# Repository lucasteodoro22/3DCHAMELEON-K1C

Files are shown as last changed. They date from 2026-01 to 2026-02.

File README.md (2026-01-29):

# 3DChameleon K1C - Sistema de Troca Automática de Filamentos





## 📋 Visão Geral

Este projeto é uma implementação adaptada do **3DChameleon Mk4** para a impressora **Creality K1/K1C**, utilizando comunicação serial integrada com o **Klipper**. O sistema permite troca automática de até 4 filamentos diferentes durante a impressão, com controle completo via interface Klipper.

### 🎯 Características Principais

- **Troca Automática**: Até 4 filamentos diferentes
- **Integração Klipper**: Controle completo via G-code
- **Sistema de Buffer**: Alimentação automática de filamento (já implementado)
- **Coletor de Purga**: Sistema inteligente de coleta de purga
- **Estado Persistente**: Salva estado entre reinicializações
- **Corte Automático**: Sequência segura de corte de filamento

### 🔧 Integrações Já Implementadas

Este projeto utiliza e adapta os seguintes sistemas já prontos:

#### 📦 **Sistema de Buffer Automático** (`FILAMENT_BUFFER_MOUNT.stl`)
- **Montagem**: Modelo STL customizado para Creality K1
- **Funcionalidade**: Alimentação automática quando buffer vazio
- **Sensores**: Microswitches NC para detecção de nível
- **Integração**: Completamente integrada ao firmware Arduino

#### 🐢 **Sistema de Buffer TurtleNeck** (`TurtleNeck-main/`)
- **Uso**: Sistema de buffer de filamento (TurtleNeck buffer)
- **Modelos**: `frame.stl`, `lid.stl`, `[a]_slide.stl`, `TN_horizontal mount.stl`
- **Integração**: Buffer de filamento compatível com montagem horizontal na Creality K1
- **Função**: Mantém reservatório de filamento para reduzir tensão na extrusora

#### 🔀 **Hub PTFE 3-para-1** (`ptfe-3-to-1-hub-model_files/`)
- **Distribuição**: `ptfe3to1hub_v2.stl` para 3 filamentos
- **Versões**: Full (`ptfe3x1_full.stl`) e Half (`ptfe3x1_half.stl`)
- **Integração**: Sistema de distribuição para múltiplos filamentos

---

## 🏗️ Arquitetura do Sistema

### Componentes Principais

#### 1. **Arduino Uno + CNC Shield v3** (`3dchameleon_serial.ino`)
- **Eixo Z**: Motor da extrusora (alimentação de filamento)
- **Eixo X**: Motor do seletor (seleção de ferramenta)
- **Servo Pin 11**: Coletor de purga (PURGA_COLETOR_PIN)
- **Sensores de filamento por ferramenta** (NC): T0=D9 (X Endstop), T1=D10 (Y Endstop), T2=D13 (SpnDir)
- **Sensor de filamento no hotend**: A3 (CoolEnd)
- **Sensor de alimentação** (NO): T1=A2 (Resume) — monitora filamento pré-carregado
- **Sensores de buffer** (NC): A0 (HOLD), A1 (ABORT)
- **Comunicação**: Serial 9600 baud com Klipper

#### 2. **Integração Klipper** (`3dchameleon_serial.cfg`)
- Macros completas de troca automática
- Sistema de estado persistente
- Controle de temperatura automático
- Sequências de corte e purga

#### 3. **Script Python** (`control_arduino.py`)
- Gerenciamento de estado persistente
- Comunicação serial com Arduino
- Armazenamento JSON independente

### Fluxo de Operação

```
Seleção de Filamento (T0-T3)
        ↓
Corte de Filamento Atual
        ↓
Remoção (Unload) + Purga
        ↓
Seleção de Novo Filamento
        ↓
Carregamento (Load) + Purga
        ↓
Retorno à Posição Anterior
```

---

## 🔧 Hardware Necessário

### Eletrônica
- **Arduino Uno R3**
- **CNC Shield v3** para Arduino Uno
- **2x Drivers A4988 ou DRV8825** (para motores stepper)
- **Servo 360°** (para coletor de purga)
- **2x Microswitches NC** (sensores de buffer: A0, A1)
- **1x Microswitch NC** (sensor de filamento no hotend: A3)
- **3x Microswitches NC** (sensores de filamento por ferramenta: T0=D9, T1=D10, T2=D13)
- **1x Microswitch NO** (opcional, sensor de alimentação T1: A2)

### Motores
- **Motor Stepper 1**: Seletor de ferramentas (NEMA 17)
- **Motor Stepper 2**: Extrusora/buffer (NEMA 17)

### Sensores
- **Sensor de filamento no hotend**: Microswitch NC (A3 - CoolEnd)
- **Sensores de filamento por ferramenta** (NC): T0=D9 (X Endstop), T1=D10 (Y Endstop), T2=D13 (SpnDir)
- **Sensor de alimentação T1** (NO, opcional): A2 (Resume)
- **Buffer Empty**: Microswitch NC (A1 - ABORT)
- **Buffer Full**: Microswitch NC (A0 - HOLD)

---

## 📁 Estrutura de Arquivos

```
3DCHAMELEON-K1C/
├── 📄 3dchameleon_serial.ino          # Firmware Arduino principal
├── 📄 3dchameleon_serial.cfg          # Configuração Klipper
├── 📄 control_arduino.py              # Script de comunicação
├── 📁 STLs/                           # Modelos 3D
│   ├── 📁 3DChameleonMk4/            # Modelos oficiais do projeto
│   │   ├── 3DChameleon 4.0 (A Part).stl
│   │   ├── 3DChameleon 4.0 (B Part).stl
│   │   ├── 3DChameleon 4.0 (Bearing Carrier).stl
│   │   ├── 3DChameleon 4.0 (Cam).stl
│   │   ├── 3DChameleon 4.0 (Electronics Enclosure).stl
│   │   ├── 3DChameleon 4.0 (PTFE Template).stl
│   │   ├── 3DChameleon 4.0 (Spacer).stl
│   │   ├── 3DChameleon 4.0 (Switch Mount).stl
│   │   ├── Creality K1 Switch Mounting Plate.stl
│   │   └── 3DChameleon4YAdapter.stl
│   ├── 📁 creality-k1-hopper-model_files/
│   │   ├── holder.stl                # Suporte do hopper Creality K1
│   │   └── hopper.stl                # Hopper Creality K1
│   ├── 📁 ptfe-3-to-1-hub-model_files/
│   │   ├── ptfe3to1hub_v2.stl        # Hub PTFE 3-para-1
│   │   ├── ptfe3x1_full.stl          # Versão completa
│   │   └── ptfe3x1_half.stl          # Versão meia
│   ├── 📁 TurtleNeck-main/           # Sistema de Buffer TurtleNeck
│   │   ├── STLs/
│   │   │   ├── [a]_slide.stl
│   │   │   ├── frame.stl
│   │   │   ├── lid.stl
│   │   └── TN_horizontal mount.stl
│   └── 📄 FILAMENT_BUFFER_MOUNT.stl   # Montagem do buffer (JÁ IMPLEMENTADO)
└── 📄 README.md                       # Esta documentação
```

---

## ✅ Sistema Já Implementado

### 🎯 Componentes Funcionais

#### 🔄 **Sistema de Buffer Automático**
- **Status**: ✅ COMPLETAMENTE IMPLEMENTADO
- **Hardware**: Arduino + sensores + motor stepper
- **Software**: Firmware integrado com detecção automática
- **STLs**: `FILAMENT_BUFFER_MOUNT.stl` + **TurtleNeck buffer** para K1

#### 🐢 **Sistema TurtleNeck (Buffer)**
- **Status**: ✅ MODELOS DISPONÍVEIS
- **Uso**: Buffer de filamento TurtleNeck para reduzir tensão
- **Montagem**: Horizontal compatível com Creality K1
- **STLs**: `frame.stl`, `lid.stl`, `slide.stl`, `mount.stl`

#### 🔀 **Hub PTFE 3-para-1**
- **Status**: ✅ SISTEMA PRONTO
- **Função**: Distribuição de 3 filamentos para o seletor
- **Versões**: Completa e meia disponíveis
- **Integração**: Compatível com sistema de troca automática

#### 🤖 **Firmware Arduino**
- **Status**: ✅ FUNCIONAL
- **Comunicação**: Serial 9600 baud com Klipper
- **Motores**: Controle X (seletor) e Z (extrusora)
- **Sensores**: Filamento no hotend (A3) + sensores por ferramenta (T0=D9, T1=D10, T2=D13) + buffer (A0, A1) + alimentação T1 (A2, opcional)
- **UNLOAD por sensor**: Comando `UNLOAD` sem distância — para quando sensor indica ausência de filamento
- **Load até sensor**: `loadUntilSensorAlimentacaoDeFilamento(toolNumber)` — carrega até sensor e retorna à ferramenta original

#### 🖥️ **Integração Klipper**
- **Status**: ✅ COMPLETA
- **Macros**: T0-T2 com troca automática
- **Estado**: Persistente entre reinicializações
- **Shell Command**: Python bridge funcionando

---

## 🛒 Lista de Materiais

### Eletrônica e Componentes

| Item | Quantidade | Valor Aproximado | Link de Compra |
|---|---|---|---|
| **Arduino Uno** | 1 | R$36 | [Mercado Livre](https://www.mercadolivre.com.br/uno-r3-smd-chip-compativel-arduino/p/MLB38492604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) |
| **CNC Shield v3** | 1 | R$ 27 | [Mercado Livre](https://www.mercadolivre.com.br/cnc-shield-v3-arduino-impressora-3d-reprap-grbl/p/MLB2039012117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) |
| **Driver A4988** | 2 | R$ 27 | [Mercado Livre](https://www.mercadolivre.com.br/2x-driver-motor-de-passo-a4988-com-dissipador-8-35v-2a/p/MLB2039737210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) |
| **Servo 360°** | 1 | R$ 38 | [Mercado Livre](https://www.mercadolivre.com.br/servo-digital-blutu-mg996r-360-metal-15kg-alto-torque-arduino/p/MLB40989790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) |
| **Microswitch NC** | 5 | R$19 | [Mercado Livre](https://www.mercadolivre.com.br/chave-fim-de-curso-kw10-b-micro-switch-com-haste-10/p/MLB44351264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) — hotend + buffer (2) + por ferramenta (3) |
| **Microswitch NO** | 1 | opcional | Sensor de alimentação T1 (A2) |
| **NEMA 17 Stepper Motor** | 2 | R$ 60 cada | [Mercado Livre](https://www.mercadolivre.com.br/motor-de-passo-nema-17-42kgf-14a-ender-3-impressora-3d/p/MLB2045385578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) |
| **PTFE Tubing 4mmx2,5mm OD** | 4m | R$ 70 | [Mercado Livre](https://www.mercadolivre.com.br/tubo-ptfe-para-bambu-lab-a1-mini-25mm-x-40mm/up/MLBU3464340835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) |
| **Conectores PTFE PC4-M10** | R$45 | [Mercado Livre](https://www.mercadolivre.com.br/kit-5-conectores-bowden-pc401-m10-pneumatico-hotend-ptfe/up/MLBU734237438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) |
| **Engrenagem MK8** | 2 | R$10 cada | [Mercado Livre](https://www.mercadolivre.com.br/1-peca-engrenagem-mk8-filamento-175mm-para-impressora-3d/up/MLBU1714610359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) |
| **Parafuso e Porcas M3x30mm** | 8 | R$23 | [Mercado Livre](https://www.mercadolivre.com.br/parafuso-com-cabeca-allen-m3-x-30mm-inox--20-pecas/up/MLBU1967887623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) |
| **Parafuso e Porcas M3x12mm** | 8 | R$20 | [Mercado Livre](https://www.mercadolivre.com.br/kit-parafuso-maquina-allen-m3-x-12mm-cilindrico-20-unidades-ciser/p/MLB47070098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) |
| **Rolamento 625zz** | 4 | R$ 39 | [Mercado Livre](https://www.mercadolivre.com.br/kit-10-micro-rolamento-625-zz--625zz-5x16x5mm--aco-carbono/up/MLBU730803302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) |
| **Rolamento 6800zz** | 2 | R$ 23 | [Mercado Livre](https://www.mercadolivre.com.br/kit-5-rolamentos-6800-zz-medidas-10x19x5mm-cinza/p/MLB56414559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) |

---

## ⚙️ Instalação e Configuração

### 1. Preparação do Hardware

#### Conexões Arduino/CNC Shield:

```cpp
// Eixo Z - Extrusora (alimentação de filamento)
#define extEnable 12   // Z_ENABLE
#define extStep 4      // Z_STEP
#define extDir 7       // Z_DIR

// Eixo X - Seletor (seleção de ferramenta)
#define selEnable 8    // X_ENABLE
#define selStep 2      // X_STEP
#define selDir 5       // X_DIR

// Servo e sensores
#define PURGA_COLETOR_PIN 11       // Coletor de purga (Z+ Endstop)
#define FILAMENT_SENSOR_PIN A3     // Sensor no hotend (CoolEnd)

// Sensores de filamento por ferramenta (NC) - UNLOAD/Load até sensor
#define FILAMENT_SENSOR_T0_PIN 9   // X Endstop
#define FILAMENT_SENSOR_T1_PIN 10  // Y Endstop
#define FILAMENT_SENSOR_T2_PIN 13  // SpnDir

// Sensor de alimentação T1 (NO, opcional)
#define FILAMENT_ALIMENTATION_SENSOR_T1_PIN A2  // Resume

// Buffer (NC)
#define BUFFER_EMPTY_PIN A1   // ABORT - buffer vazio
#define BUFFER_FULL_PIN A0   // HOLD - buffer cheio
```

#### Impressão dos Componentes:

1. **Estrutura Principal**: Imprimir peças A e B do 3DChameleon
2. **Suporte Creality K1**: Usar `holder.stl` e `hopper.stl`
3. **Sistema Buffer**: Usar `FILAMENT_BUFFER_MOUNT.stl`
4. **Hub PTFE**: Usar `ptfe3to1hub_v2.stl` para distribuição de filamentos

### 2. Instalação do Firmware

1. **Carregar `3dchameleon_serial.ino`** no Arduino Uno
2. **Verificar comunicação serial** (9600 baud)
3. **Testar homing** do seletor

### 3. Configuração Klipper

1. **Copiar `3dchameleon_serial.cfg`** para pasta config do Klipper
2. **Instalar shell_command module** (se necessário)
3. **Copiar `control_arduino.py`** para `/usr/data/printer_data/config/`
4. **Dar permissões de execução**: `chmod +x control_arduino.py`
5. **Reinicializar Klipper**: `FIRMWARE_RESTART`

### 4. Calibração

#### Calibração de Passos por mm:
```cpp
const float STEPS_PER_MM = 151.0; // Ajustar conforme necessário
```

#### Calibração de Posições:
- Executar `CFS_HOME` para homing
- Testar seleção `T0`, `T1`, `T2` sequencialmente
- Verificar posições idle corretas

---

## 🎮 Como Usar

### Comandos Básicos

#### Troca de Filamentos:
```gcode
T0    ; Seleciona filamento 0 (completo com corte/purga)
T1    ; Seleciona filamento 1
T2    ; Seleciona filamento 2
```

#### Load e Unload (comandos serial para o Arduino):
- **LOAD \<mm\>**: Carrega filamento até sensor do hotend, depois avança distância em mm
- **UNLOAD**: Descarrega filamento até sensor da ferramenta indicar ausência (parada automática) — **sem precisar informar distância**
- **UNLOAD \<mm\>**: Descarrega por distância fixa (modo legado)
- **UNLOAD_RETRACAO \<mm\>**: Descarrega com velocidade fixa (5 mm/s) para sincronização com retração do Klipper

A função **loadUntilSensorAlimentacaoDeFilamento(toolNumber)** carrega filamento até o sensor da ferramenta detectar presença; move o seletor para a ferramenta, carrega até o sensor e retorna para a posição original.

#### Comandos de Controle:
```gcode
CFS_HOME          ; Home do seletor
CFS_IDLE          ; Move para posição idle
CFS_STATUS        ; Status do Arduino
```

#### Sistema de Purga:
```gcode
CFS_CUT           ; Posiciona para corte físico
CFS_PURGE_START   ; Ativa coletor + posiciona
CFS_PURGE_FINISH  ; Purga filamento + desativa
```

### Uso no Slicer

#### PrusaSlicer - Tool Change G-code:
```gcode
; Troca para próximo filamento
CFS_T{next_extruder}
M117 "Filamento {next_extruder} carregado"
```

### Monitoramento de Estado

```gcode
CURRENT_FILAMENT          ; Mostra filamento atual
SET_CURRENT_FILAMENT T=1  ; Define filamento atual
LOAD_CURRENT_FILAMENT      ; Carrega estado salvo
```

---

## 🔧 Sistema de Buffer Automático

### 🐢 **O que é TurtleNeck?**

O **TurtleNeck** é um sistema de buffer de filamento inteligente que:

- **Mantém um reservatório** de filamento entre o spool e a extrusora
- **Reduz a tensão** no filamento durante movimentos rápidos da cabeça
- **Previne emaranhamento** e quebra do filamento
- **Melhora a qualidade** da impressão com filamentos flexíveis
- **Compatível** com montagem horizontal na Creality K1

### 📦 **Componentes do Sistema de Buffer**

1. **FILAMENT_BUFFER_MOUNT.stl**: Montagem específica para Creality K1
2. **TurtleNeck Buffer**: Sistema de reservatório inteligente
3. **Sensores**: Microswitches NC para detecção automática de nível
4. **Firmware Arduino**: Controle automático de alimentação

### 🔄 **Funcionamento Automático**

- **Detecção**: Sensor identifica quando buffer está vazio
- **Alimentação**: Motor stepper alimenta filamento automaticamente
- **Monitoramento**: Verificação contínua durante impressão
- **Proteção**: Timeout de inatividade para economia de energia

### Funcionalidades

- **Alimentação Automática**: Buffer se recarrega quando vazio
- **Monitoramento Contínuo**: Verificação a cada 200ms
- **Estado Persistente**: Sobrevive a reinicializações
- **Proteções**: Timeout de inatividade (2 minutos)

### Lógica de Operação

1. **Detecção**: Sensor identifica buffer vazio
2. **Verificação**: Confirma filamento no hotend
3. **Posicionamento**: Move seletor para ferramenta ativa
4. **Alimentação**: Extrusora alimenta até sensor "full"
5. **Confirmação**: Log de operação bem-sucedida

### Configurações

```cpp
#define BUFFER_CHECK_INTERVAL 100   // Verificação a cada 100ms
#define IDLE_TIMEOUT 120000         // 2 minutos sem atividade
const float STEPS_PER_MM = 151.0;   // Calibração passos/mm
```

### Load/Unload com sensores por ferramenta

- **UNLOAD** (sem distância): usa o sensor da ferramenta ativa (T0→D9, T1→D10, T2→D13) para parar quando o filamento sair (sensor NC: LOW = sem filamento).
- **loadUntilSensorAlimentacaoDeFilamento(toolNumber)**: move para a ferramenta, carrega até o sensor detectar filamento (NC: HIGH = presente), depois retorna para a ferramenta original.
- Sensores NC: HIGH = filamento presente, LOW = sem filamento. Sensor de alimentação T1 (NO): HIGH = presente, LOW = ausente.

---

## 🛠️ Sistema de Purga Inteligente

### Sequência de Purga

1. **Corte**: Posicionamento seguro para corte físico
2. **Ativação**: Servo abre coletor de purga
3. **Posicionamento**: Bico vai para área de purga
4. **Extrusão**: Purga filamento residual
5. **Limpeza**: Movimentos de vai-e-vem
6. **Desativação**: Fecha coletor

### Posições Configuráveis

```python
# Posições de corte (sequência segura)
x_corte_1: 50.0, y_corte_1: 200.0    # Posição inicial
x_corte_2: 50.0, y_corte_2: 226.0    # Extensão Y
x_corte_3: 6.0, y_corte_3: 226.0     # Extensão X
x_corte_final: 50.0, y_corte_final: 226.0

# Posições de purga
x_purga: 160.0, y_purga: 226.0       # Área de purga
z_min_purga: 36.0                    # Altura segura
```

---

## 📊 Estado Persistente

### Arquivos de Estado

- **Klipper**: `/usr/data/printer_data/config/current_filament.cfg`
- **Python**: `/usr/data/printer_data/config/chameleon_state.json`

### Funcionalidades

- **Auto-carregamento**: Estado carregado automaticamente na inicialização
- **Backup duplo**: Tanto Klipper quanto script Python
- **Sobrevivência**: Mantém estado após crashes/reinicializações
- **Sincronização**: RAM e arquivo sempre sincronizados

### Comandos de Gerenciamento

```gcode
LOAD_CURRENT_FILAMENT      ; Carrega do arquivo para RAM
CURRENT_FILAMENT          ; Mostra estado atual
SET_CURRENT_FILAMENT T=1  ; Define e salva
```

---

## 🔧 Manutenção e Troubleshooting

### Problemas Comuns

#### 1. Seletor não move
- Verificar conexões motor X (seletor)
- Testar `CFS_HOME`
- Verificar calibração de passos

#### 2. Buffer não alimenta
- Verificar sensor de filamento (A3)
- Testar sensores de buffer (A0/A1)
- Verificar posição do seletor

#### 3. Comunicação serial falha
- Verificar cabo USB Arduino
- Confirmar baud rate (9600)
- Testar `CFS_STATUS`

#### 4. Estado não persiste
- Verificar permissões do arquivo JSON
- Confirmar caminho correto
- Testar script Python isoladamente

### Calibração

#### Passos por mm:
```cpp
// Testar com comando LOAD/UNLOAD conhecido
// Medir filamento real vs esperado
// Ajustar STEPS_PER_MM conforme necessário
```

#### Posições do Seletor:
```gcode
CFS_HOME          ; Estabelece posição 0
T0, T1, T2        ; Testa sequencialmente
CFS_IDLE          ; Verifica posições idle
```

---

## 📈 Logs e Debug

### Níveis de Log

- **Serial Arduino**: Status em tempo real
- **Klipper Console**: Comandos e respostas
- **Estado**: Persistência de variáveis

### Comandos de Debug

```gcode
CFS_TEST_LOAD     ; Testa sistema completo
M118 "Debug message"  ; Logs customizados
CFS_STATUS        ; Status do Arduino
```

---

## 🤝 Contribuição

### Baseado em

Este projeto é uma adaptação do **3DChameleon Mk4** original:

- **Autor Original**: William J. Steele
- **Licença**: MIT
- **Repositório**: [3DChameleon GitHub](https://github.com/3DChameleon/3DChameleon)
- **Documentação**: Incluída na pasta `3DChameleonMk4/`

### Modificações Implementadas

#### 🔧 **Adaptações de Hardware**
1. **Arduino Uno + CNC Shield**: Remoção dependência SX1509
2. **Motores Stepper**: Controle direto via drivers A4988
3. **Sensores NC**: Microswitches para detecção de filamento/buffer

#### 📦 **Integrações Já Prontas Utilizadas**
1. **Sistema de Buffer**: `FILAMENT_BUFFER_MOUNT.stl` adaptado + **TurtleNeck buffer**
2. **TurtleNeck**: Sistema de buffer de filamento para reduzir tensão na extrusora
3. **Hub PTFE 3-para-1**: Distribuição `ptfe3to1hub_v2.stl`
4. **3DChameleon Base**: Estrutura A/B Parts + componentes

#### 💻 **Desenvolvimento de Software**
1. **Integração Klipper**: Comunicação serial completa
2. **Sistema Buffer**: Automação de alimentação com sensores
3. **Estado Persistente**: JSON independente do Klipper
4. **Coletor de Purga**: Servo 360° para Creality K1
5. **Macros Automáticas**: T0-T2 com troca completa
6. **Configuração Creality K1**: Perfis específicos

## 📜 Licença

Este projeto mantém a **Licença MIT** do projeto original 3DChameleon.

```
Copyright 2024 William J. Steele (3DChameleon Original)
Adapted for Creality K1 by [Your Name]

Permission is hereby granted, free of charge, to any person obtaining a copy
of this software and associated documentation files (the "Software"), to deal
in the Software without restriction, including without limitation the rights
to use, copy, modify, merge, publish, distribute, sublicense, and/or sell
copies of the Software, and to permit persons to whom the Software is
furnished to do so, subject to the following conditions:

The above copyright notice and this permission notice shall be included in all
copies or substantial portions of the Software.
```

---

### Documentação Adicional

- [Klipper G-code Shell Command](https://github.com/dw-0/kiauh/blob/master/docs/gcode_shell_command.md)
- [3DChameleon Original Documentation](https://github.com/3DChameleon/3DChameleon)
- [Creality K1 Integration](https://www.creality.com/products/creality-k1)
- [Turtle Neck](https://github.com/ArmoredTurtle/TurtleNeck)
- [BOM Completa 3DChameleon Mk4](STLs/3DChameleonMk4/3DChameleon%20Mk4%20Electronics/BOM_3D-Chameleon-MK4_2024-12-13.csv)

---

## 🔄 Changelog

### v1.1 - Sensores por ferramenta e UNLOAD/Load por sensor
- ✅ **Sensores de filamento por ferramenta** (NC): T0=D9, T1=D10, T2=D13 (X/Y Endstop, SpnDir)
- ✅ **UNLOAD sem distância**: Comando `UNLOAD` para automaticamente até sensor indicar ausência de filamento
- ✅ **loadUntilSensorAlimentacaoDeFilamento(toolNumber)**: Carrega até sensor da ferramenta e retorna à posição original
- ✅ **Sensor de alimentação T1** (NO): A2 (Resume) para monitorar filamento pré-carregado
- ✅ **Documentação e comentários**: Código e README em português; pinos e lógica NC/NO documentados

### v1.0 - Adaptação Completa para K1/K1C
- ✅ **Sistema de Buffer**: Integração completa com `FILAMENT_BUFFER_MOUNT.stl` + **TurtleNeck buffer**
- ✅ **TurtleNeck**: Sistema de buffer de filamento para reduzir tensão na extrusora
- ✅ **Hub PTFE 3-para-1**: Distribuição `ptfe3to1hub_v2.stl` implementada
- ✅ **Adaptação Arduino Uno + CNC Shield**: Sem dependência SX1509
- ✅ **Integração Klipper completa**: Comunicação serial 9600 baud
- ✅ **Estado persistente independente**: JSON + Klipper save_variables
- ✅ **Coletor de purga servo 360°**: Sequência automática
- ✅ **Macros T0-T2**: Troca automática com corte e purga
- ✅ **Configuração específica Creality K1/K1C**: Perfis otimizados

---

## 🚀 Status do Projeto

### ✅ **Pronto para Uso**

| Componente | Status | Descrição |
|---|---|---|
| **Sistema de Buffer** | ✅ Funcional | Alimentação automática com `FILAMENT_BUFFER_MOUNT.stl` |
| **Sensores por ferramenta** | ✅ Implementado | T0=D9, T1=D10, T2=D13 — UNLOAD/Load até sensor |
| **UNLOAD por sensor** | ✅ Implementado | Parada automática quando filamento sai (sem distância) |
| **Load até sensor** | ✅ Implementado | loadUntilSensorAlimentacaoDeFilamento + retorno à ferramenta |
| **TurtleNeck (Buffer)** | ✅ Modelos Disponíveis | Sistema de buffer TurtleNeck para filamento |
| **Hub PTFE 3-para-1** | ✅ Implementado | Distribuição de filamentos `ptfe3to1hub_v2.stl` |
| **Firmware Arduino** | ✅ Completo | Serial + motores + sensores NC/NO documentados |
| **Configuração Klipper** | ✅ Funcional | Macros T0-T2 + estado persistente |
| **Estrutura 3DChameleon** | ✅ Adaptada | Peças A/B + componentes para K1 |

---

*Este projeto é uma adaptação independente mantendo compatibilidade com o ecossistema 3DChameleon original.*

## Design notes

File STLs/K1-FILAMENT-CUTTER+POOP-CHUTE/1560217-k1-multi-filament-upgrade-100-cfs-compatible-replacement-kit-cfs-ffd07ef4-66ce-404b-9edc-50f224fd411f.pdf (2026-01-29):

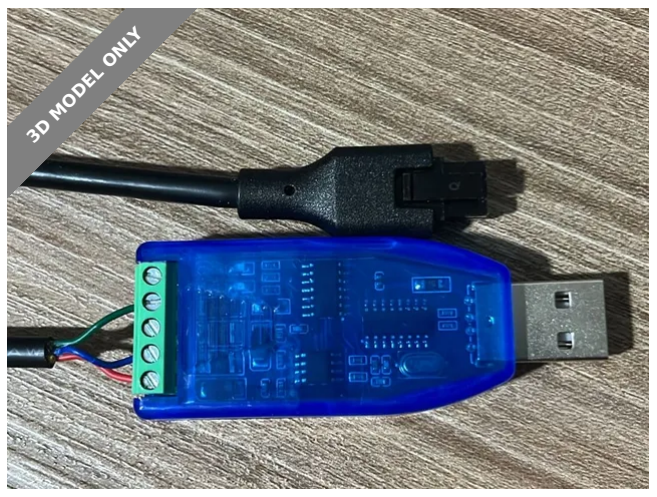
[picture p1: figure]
3D MODEL ONLY

## Summary

Multi-filament upgrade for Creality K1 / K1 Max / K1C Includes filament cutter block, sensors, purge chute and RS485-USB

3D Printers (https://printables.com/model?categoryId=1) > Creality Parts & Upgrades (https://printables.com/model?categoryId=135)

Tags: | extruder | mmu | 3dchameleon | upgradekit | k1
k1max | upgradecreality | ender3v3 | k1c | cfs | k1series
k1se | picommu | cfsupgradekit | cfsmods

Este é um mod completo de reposição do CFS, incluindo cortador de filamento + sensor de corte, descarga de purga e cabo USB do CFS, totalmente compatível com a extrusora original da Creality.

Desenvolvi esse projeto para permitir impressão multicolor com baixo custo, peças simples e fácil manutenção — sem depender do kit original caro da Creality.

Além de quê, pode ser usado em conjunto com outros MMU, como 3dchameleon, e pico MMU

Igor Darin (https://printables.com/@IgorDarin_2952534)

## K1 Multi-Filament Upgrade ( 100% CFS-Compatible) replacement KIT CFS

VIEW IN BROWSER (https://printables.com/model/1560217-k1-multi-filament-upgrade-100-cfs-compatible-repla)

updated 18. 1. 2026 | published 18. 1. 2026

### 0 Extrusora!

Este mod precisa de uma extrusora com sensor de filamento funcionando.

Recomendo imprimir este mod antes de tudo:
Sensor de filamento para extrusora:

Lista de Materiais

Extrusora original da sua impressora
1× Micro switch D2F-L (ou compatível)
(2 unidades se for usar também o mod do sensor de filamento acima) 2× Insert M3
3× Parafusos M3x10
1× Parafuso M2x10
1× Conector JST 1.25 – 5 pinos
1× Conector JST 1.25 – 3 pinos (sensor de filamento do mod acima) 1× Apontador de lápis
1× Parafuso pequeno do apontador
1× Mola 22x5 mm

Montagem Resumida

### 1 Preparando o cabo

Passe os fios do conector JST 1.25 (5 pinos) por dentro do bloco do cortador.

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
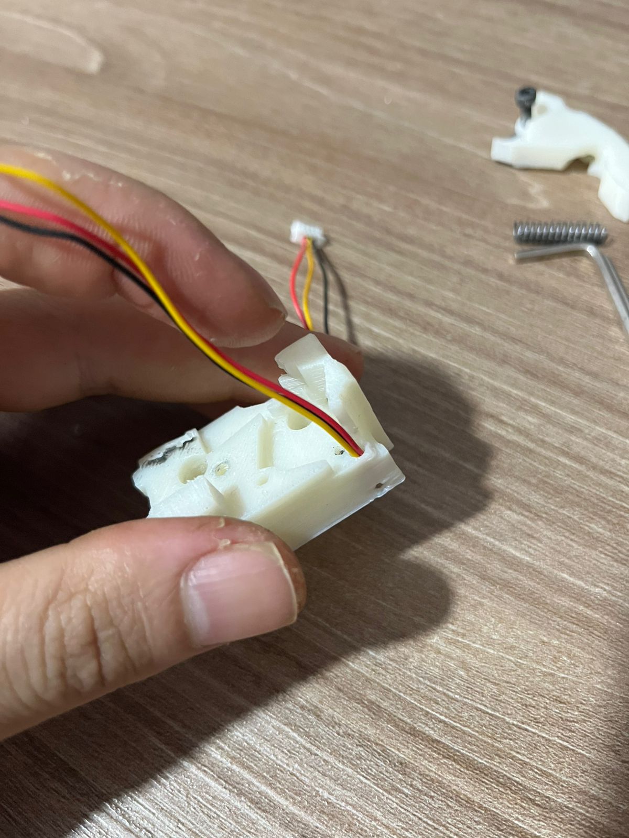
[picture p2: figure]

### 2 Soldando o micro switch (D2F-L)

C (COM) → fio amarelo → SINAL
NO → fio vermelho → +5V
NC → fio preto → GND

•
•
•

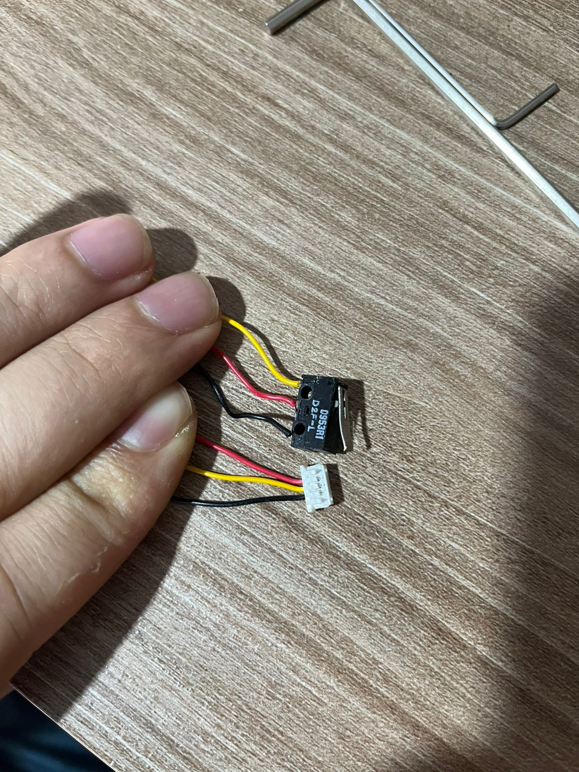
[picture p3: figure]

Remova os cabo do canto do conector, não iremos utilizar, somente o 3 do meio.

### 3 Preparando a carcaça da extrusora

Na carcaça de engrenagens da extrusora original existem 2 furos de fábrica embaixo dela
(Obrigado Creality, facilitou nossa vida 😎)

Faça a rosca nesses dois furos usando os parafusos M3x10. Depois retire os parafusos.

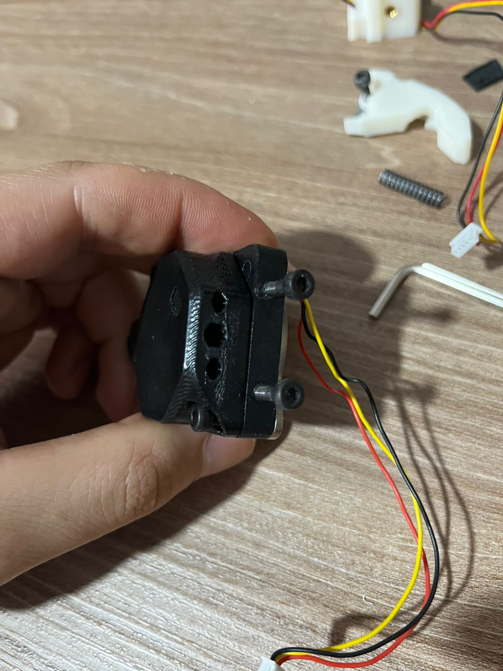
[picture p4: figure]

### 4 Fixando o bloco do cortador

Coloque os parafusos nos furos do bloco cortador, posicione o bloco na carcaça
e parafuse com cuidado (não aperte demais, é plástico).

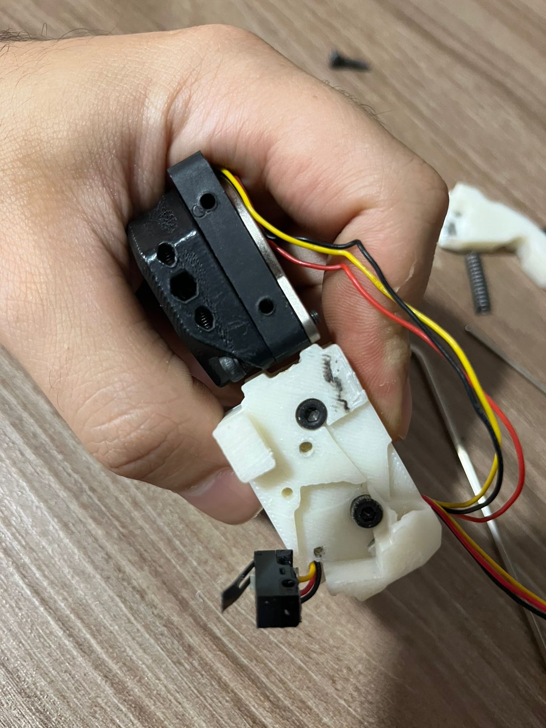
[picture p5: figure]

### 5 Instalando o micro switch

Posicione o D2F-L no local correto e fixe com o parafuso M2x10 (Pode usar dois parafusos se quiser, mas um só já segura bem)

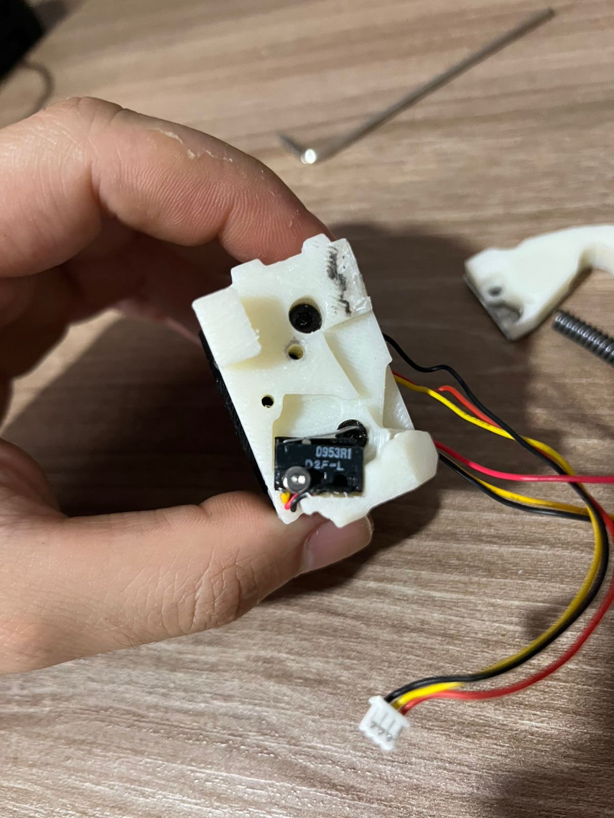
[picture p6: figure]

### 6 Preparando a lâmina

Do apontador de lápis, retire:

A lâmina
O parafuso de fixação

Coloque o parafuso no furo lateral do cortador (ele serve como apoio e segurança da lâmina),
alinhe a lâmina, pingue um pouco de supercola e aguarde secar.

•
•

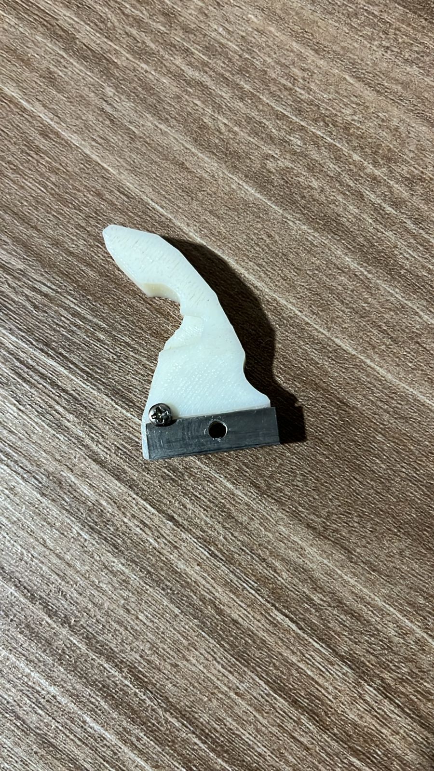
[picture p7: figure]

### 7 Montagem final

Coloque a mola 22x5 mm no braço de corte, posicione no bloco e fixe com M3x10 ou M3x12.

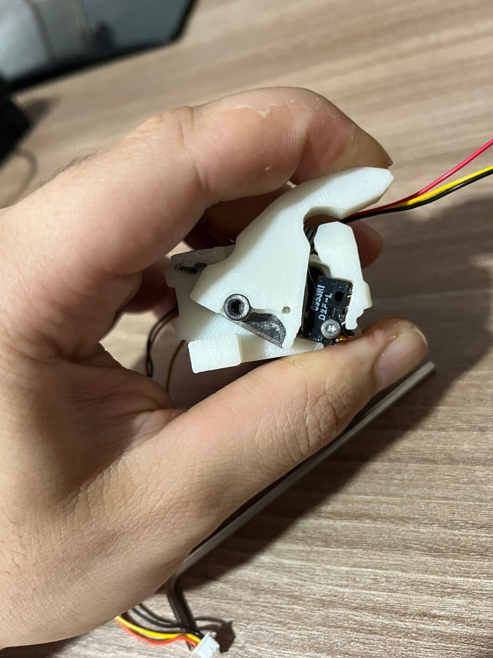
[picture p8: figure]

OBS* Note que o switch só deve ser acionado quando o filamento for completamente cortado ok? se nao for acionado, entorte a base de aço dele.

Pronto!

Agora você tem um cortador de filamento funcional, barato, robusto e perfeito para usar com CFS.

Muito mais eficiente que o original...
e custando praticamente nada 😈
Status do Cortador ⚙

Este projeto ainda está em desenvolvimento . Ajustes mecânicos, melhorias no sistema de corte e refinamentos no sensor podem ocorrer ao longo do tempo.

### 0 Cabo de Reposição USB → RS485

Para CFS (Creality K1 / K1 Max / K1C)

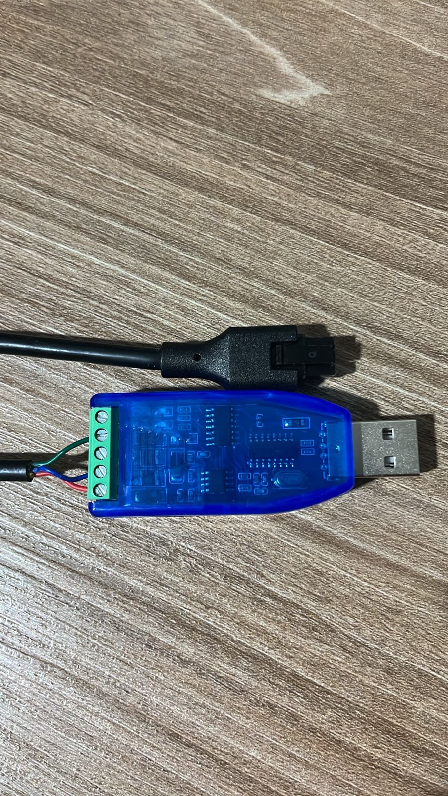
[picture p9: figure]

Este guia mostra como montar um cabo de reposição do CFS usando um conversor RS485 → USB, economizando uma grana absurda em relação ao cabo original da Creality.

Lista de Peças

1× Cabo CFS RS485
1× Conversor RS485 → USB

Use qualquer conversor que tenha A, B e GND (Terra).

Eu usei o famoso “azulzinho” e paguei incríveis R$ 19,00 (~US$ 3) 😎
Ele tem 5 pinos: A, B, GND, GND e +5V

Vamos usar somente: A, B e GND

Montagem

### 1 Preparando o cabo

Corte uma das extremidades do cabo CFS e separe apenas 3 fios ( descubra usando um multímetro)
(os outros não serão usados).

•
•

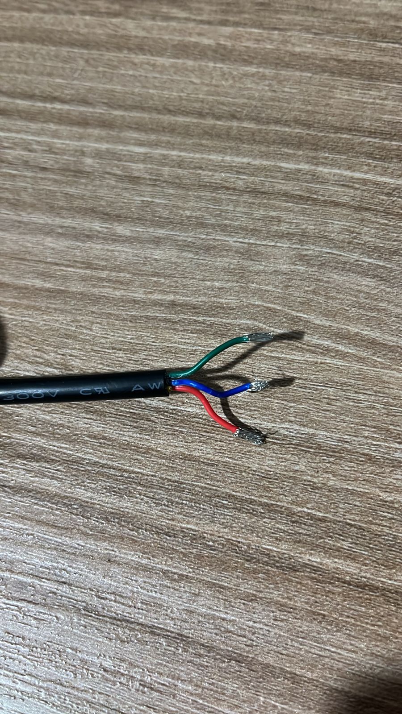
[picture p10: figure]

### 2 Mapeamento dos pinos do conector CFS

O conector possui 6 pinos:

### 3 em cima 3 embaixo

Somente 3 deles são usados para o RS485:

•
•

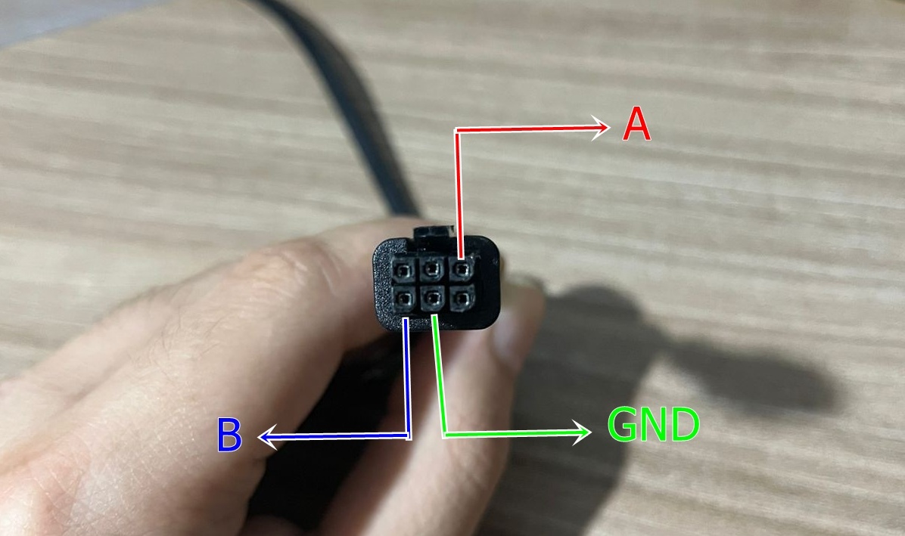
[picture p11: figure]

Mapeamento que vamos usar:

Conector CFS | Função | Cor no meu cabo
Superior direito (3o pino de cima) | A | Vermelho
Inferior esquerdo (1o pino de baixo) | B | Azul
Inferior central (2o pino de baixo) | GND | Verde

### 3 Ligação no conversor RS485 → USB

Agora é só ligar:

A → A
B → B
GND → GND

Simples assim.

•
•
•

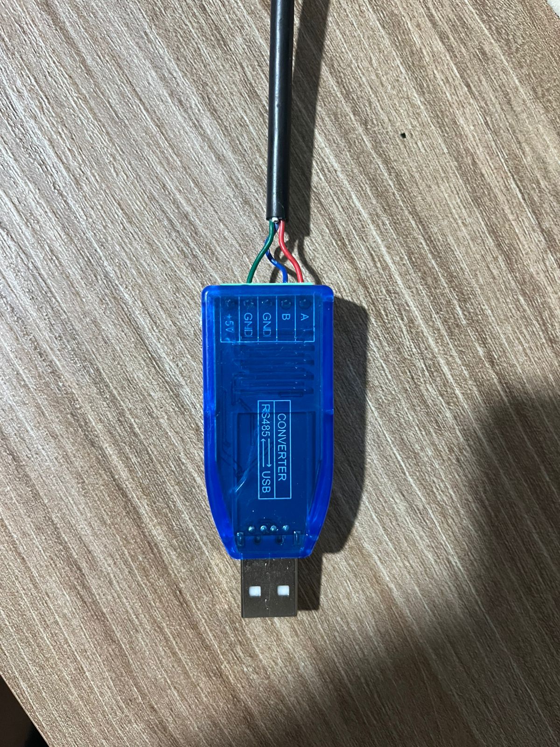
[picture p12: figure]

⚠ OBS IMPORTANTE

As cores do seu cabo podem ser diferentes das minhas. Use o multímetro em teste de continuidade para identificar corretamente os fios.

Não me responsabilizo por ligações erradas
(ligar A no B é o equivalente eletrônico de colocar meia no chinelo errado 😅)

Pronto!

Agora você tem um cabo CFS funcional,
por menos da metade do preço do original da Creality.

E funcionando igual.
Sem frescura.
Sem pagar imposto emocional.
Poop shoot

#Aguardem, ainda estou mudando algumas coisas.

## Model files

⚠ Aviso Importante / Isenção de Responsabilidade 😐

Este mod é fornecido “como está”, sem garantias.
Não me responsabilizo por quaisquer danos causados à impressora, extrusora, eletrônica, filamentos ou outros componentes decorrentes da instalação ou uso ⚠ .

A montagem e utilização são de total responsabilidade do usuário, sendo recomendado apenas para pessoas com conhecimento técnico em impressão 3D.

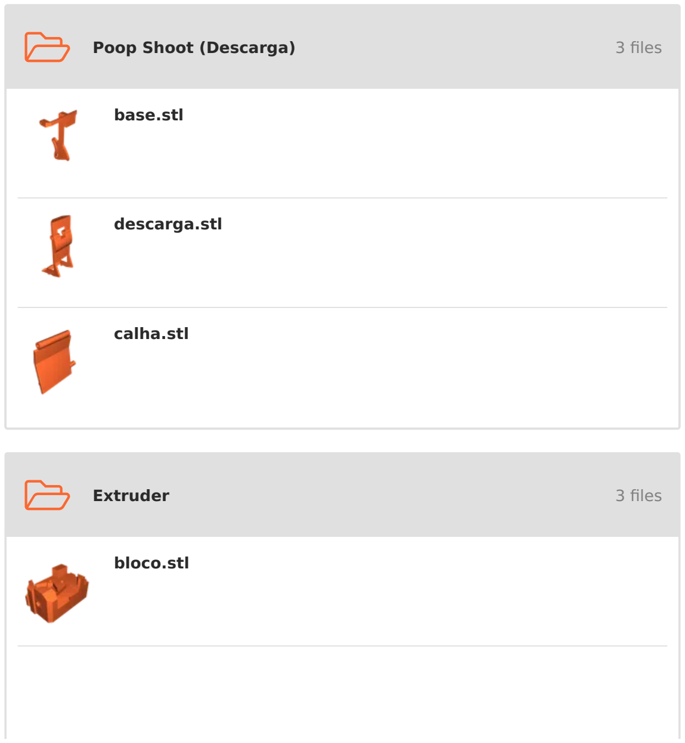
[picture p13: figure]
Poop Shoot (Descarga); 3 files; Extruder; base.stl; descarga.stl; calha.stl; bloco.stl

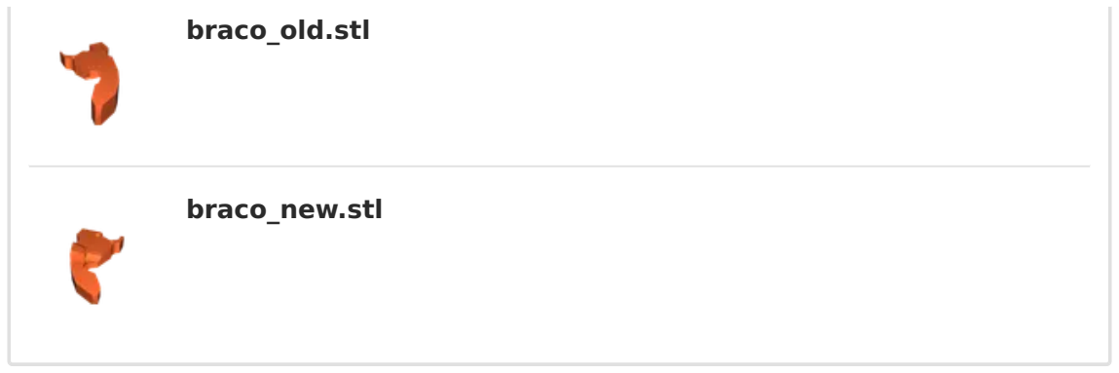
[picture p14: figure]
braco_old.stl; braco_new.stl

## License

This work is licensed under a
Creative Commons (4.0 International License)

Attribution-NonCommercial (http://creativecommons.org/licenses/by-nc/4.0/)

✖ | Sharing without ATTRIBUTION
✔ | Remix Culture allowed
✖ | Commercial Use
✖ | Free Cultural Works
✖ | Meets Open Definition

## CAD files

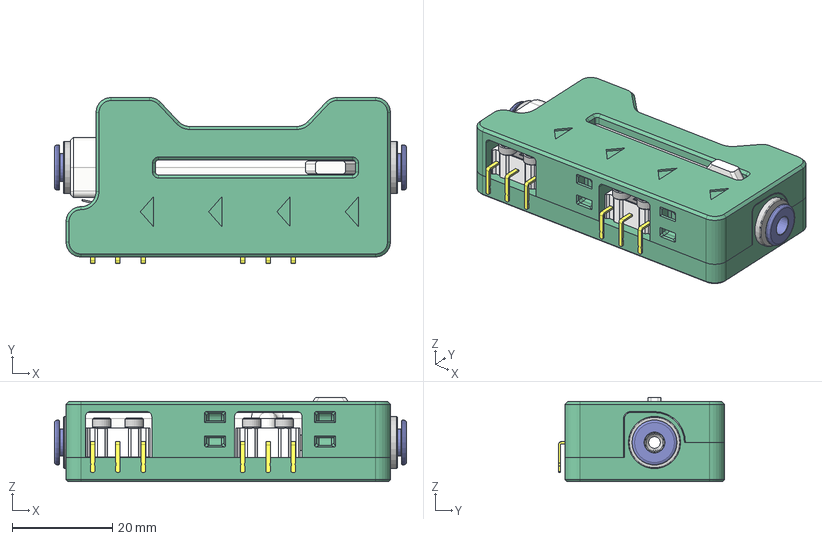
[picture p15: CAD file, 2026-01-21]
STLs/TurtleNeck-main/TN_Assembled.step
70.4 x 33.2 x 16.8 mm
D2F_Bottom^D2F-L_Right_Angled
D2F_Top^D2F-L_Right_Angled
D2F_Button^D2F-L_Right_Angled
D2F_Pin_Angled^D2F-L_Right_Angled x 4
D2F_Hinge^D2F-L_Right_Angled
D2F_Bottom^D2F-L_Left_Angled
D2F_Top^D2F-L_Left_Angled
D2F_Button^D2F-L_Left_Angled
D2F_Pin_Angled^D2F-L_Left_Angled x 4
D2F_Hinge^D2F-L_Left_Angled
M3 Threaded Insert x 4
91290A113_NO THREADS_Alloy Steel Socket Head Screw x 4
Plunger
Collet Body
Seal Retainer
Grab Ring
Plunger_1
Collet Body_1
Seal Retainer_1
Grab Ring_1
M2x10 STS x 4
lid
Frame
Slide

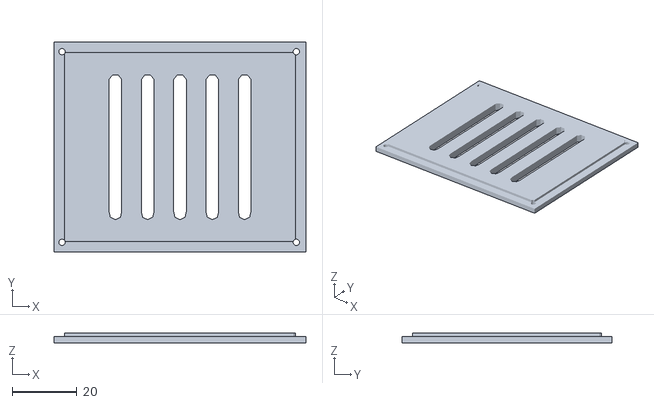
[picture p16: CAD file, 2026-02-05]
STLs/FILAMENT_BUFFER_MOUNT_TOP.stl
78.0 x 65.0 x 3.00

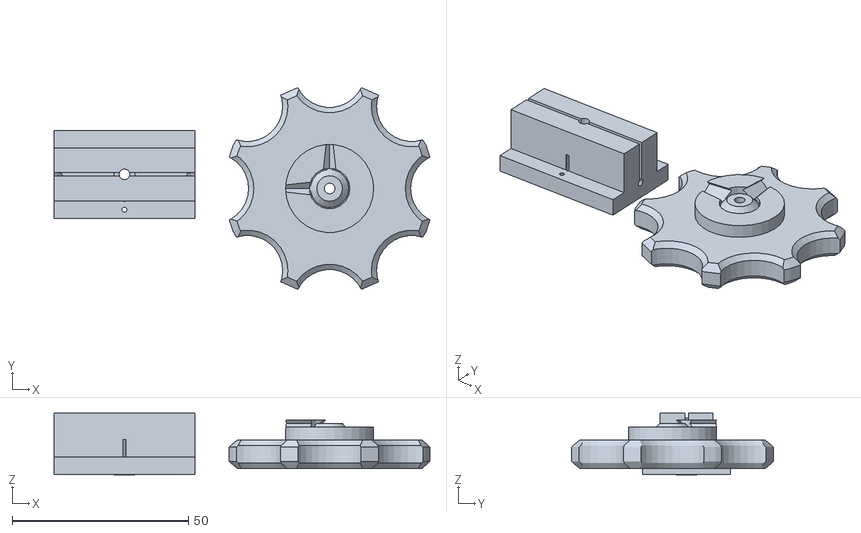
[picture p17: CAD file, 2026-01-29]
STLs/K1-FILAMENT-CUTTER+POOP-CHUTE/Enrolador de Molas/enrolador-3mm.stl
106.7 x 57.2 x 17.5

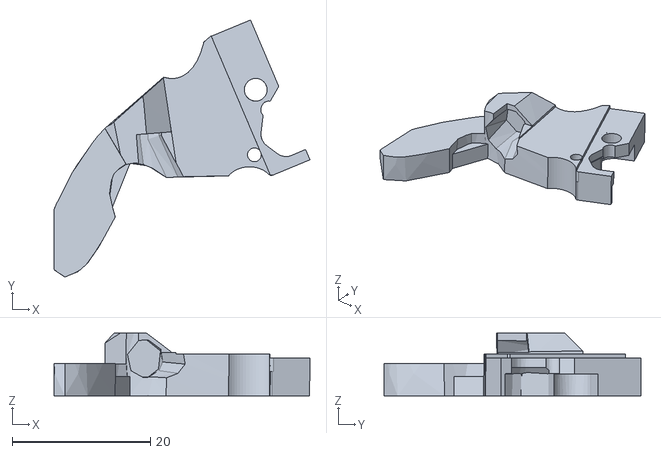
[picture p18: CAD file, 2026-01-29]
STLs/K1-FILAMENT-CUTTER+POOP-CHUTE/Extruder/braco_new.stl
37.1 x 37.2 x 9.10

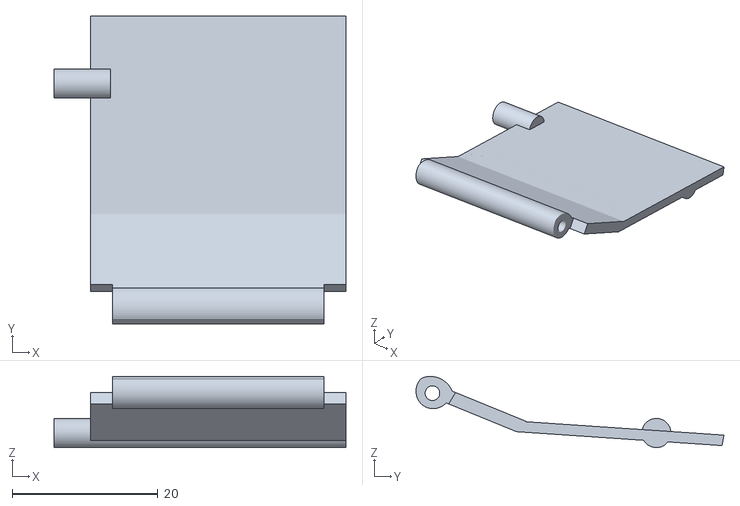
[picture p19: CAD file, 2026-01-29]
STLs/K1-FILAMENT-CUTTER+POOP-CHUTE/Poop Shoot (Descarga)/calha.stl
40.0 x 42.2 x 9.76

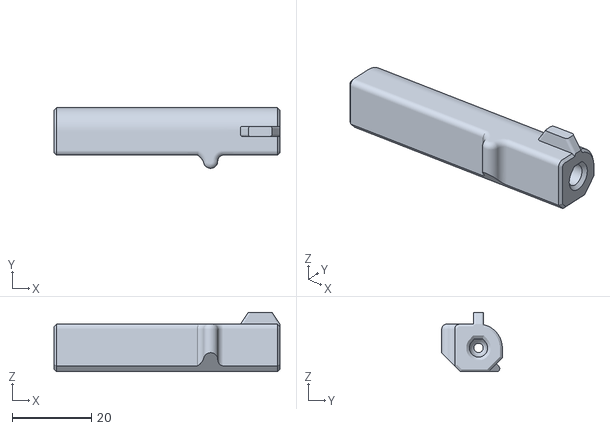
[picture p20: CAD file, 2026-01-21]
STLs/TurtleNeck-main/STLs/[a]_slide.stl
57.0 x 15.3 x 15.0

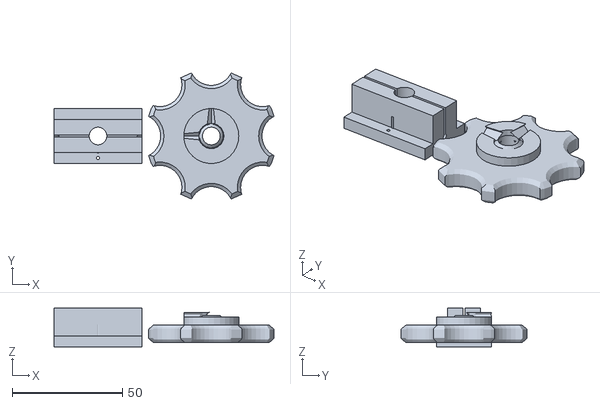
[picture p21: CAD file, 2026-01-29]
STLs/K1-FILAMENT-CUTTER+POOP-CHUTE/Enrolador de Molas/enrolador-8mm.stl
99.9 x 57.2 x 17.5

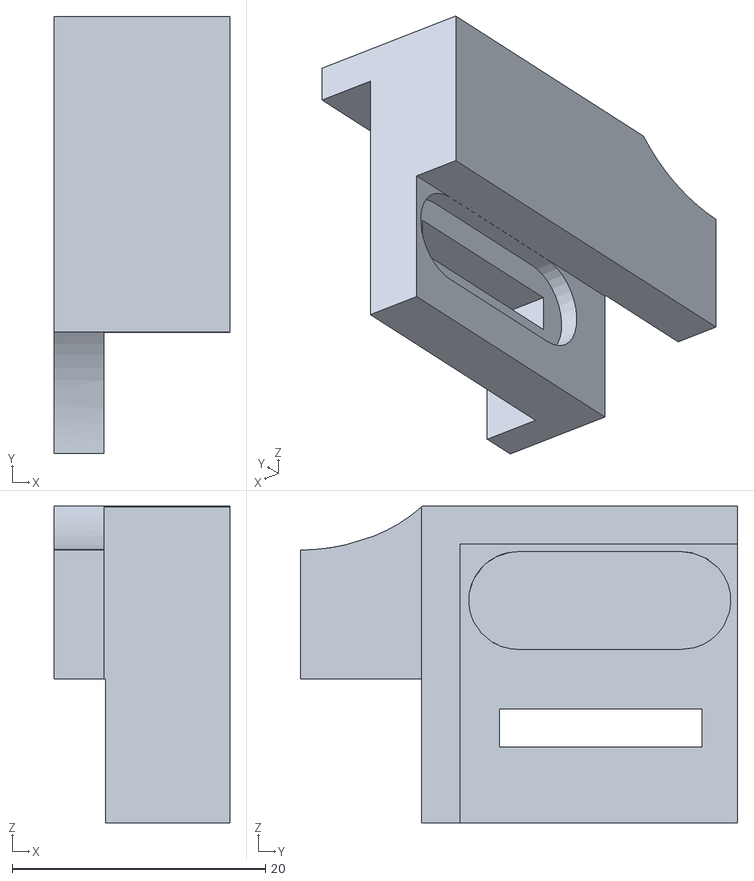
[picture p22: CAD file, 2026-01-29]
STLs/K1-FILAMENT-CUTTER+POOP-CHUTE/Extruder/batente.stl
13.9 x 34.5 x 25.0

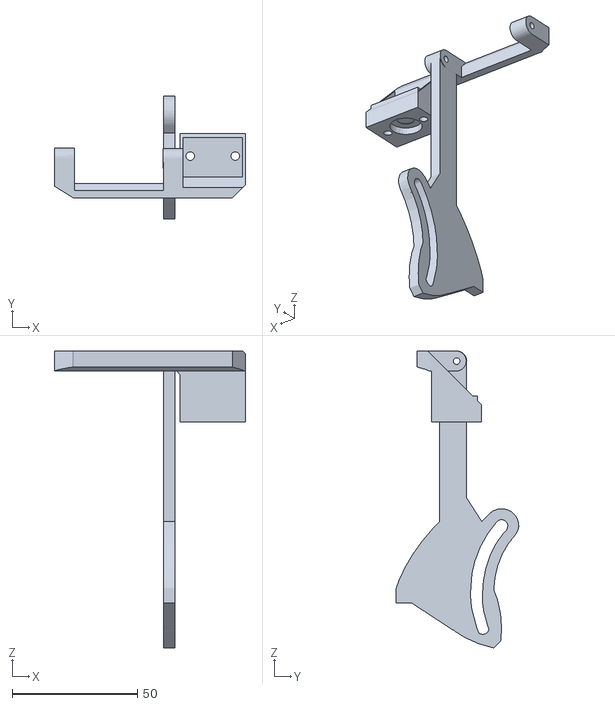
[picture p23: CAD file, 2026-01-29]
STLs/K1-FILAMENT-CUTTER+POOP-CHUTE/Poop Shoot (Descarga)/base.stl
76.4 x 49.0 x 118.6

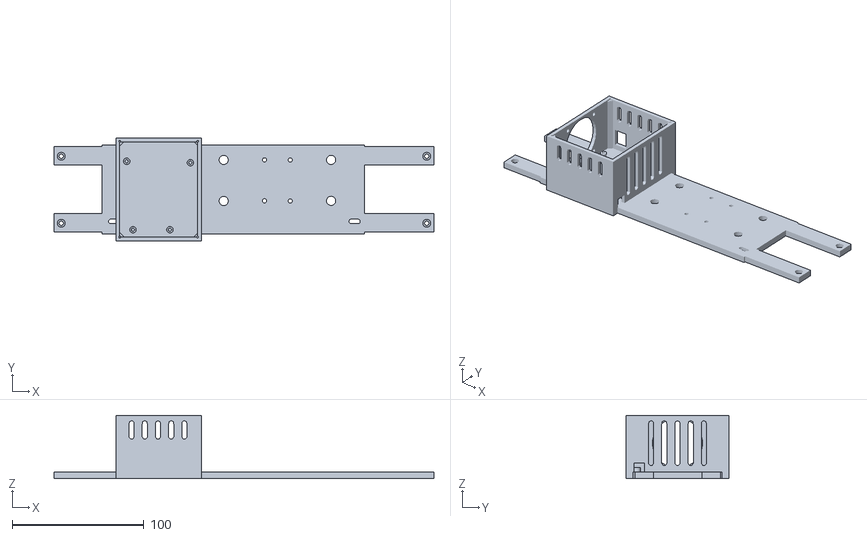
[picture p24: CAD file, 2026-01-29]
STLs/MFS-3DCHAMELEON-MOUNT.stl
288.0 x 78.0 x 47.9

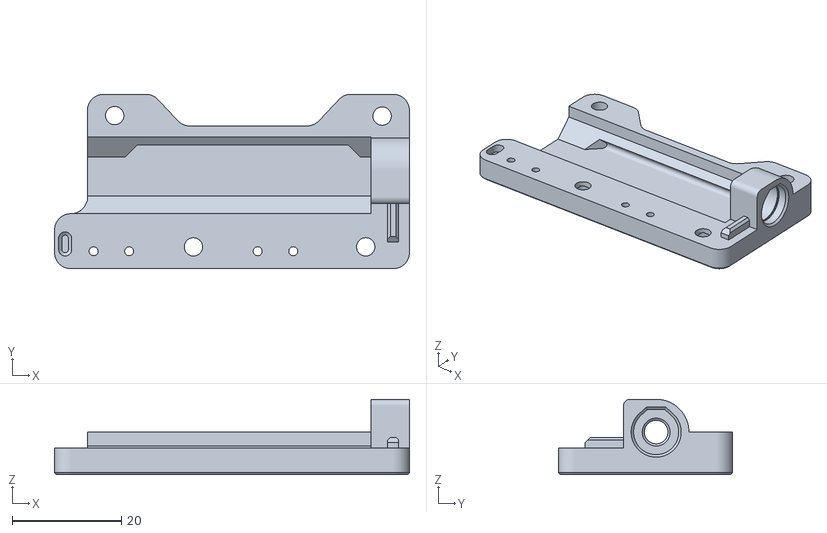
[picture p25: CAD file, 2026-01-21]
STLs/TurtleNeck-main/STLs/frame.stl
64.9 x 31.9 x 13.8

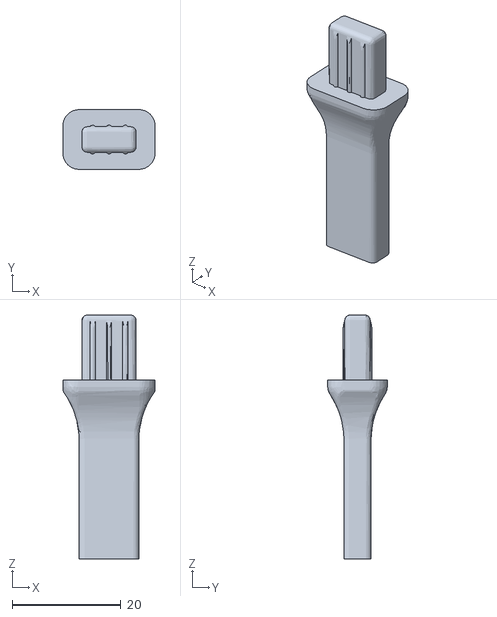
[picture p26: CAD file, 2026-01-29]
STLs/COLETOR-FILAMENTO_1.stl
17.0 x 11.0 x 44.9

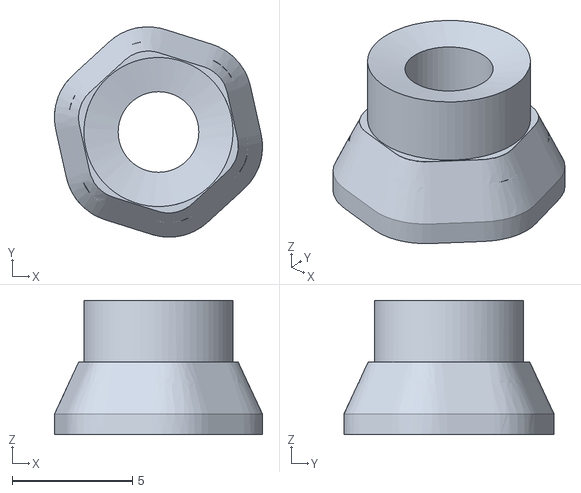
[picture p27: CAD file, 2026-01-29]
STLs/K1-FILAMENT-CUTTER+POOP-CHUTE/Extruder/guia-do-bico.stl
8.65 x 8.75 x 5.59

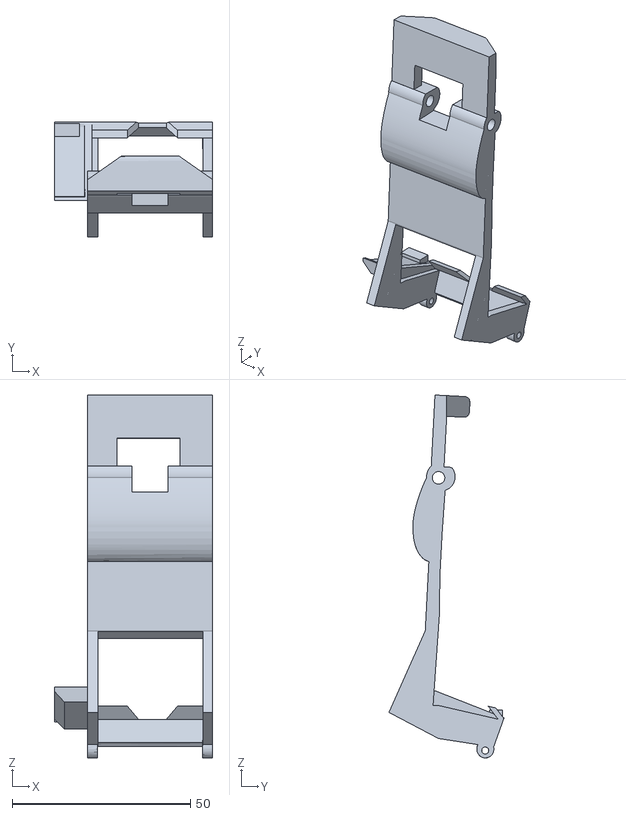
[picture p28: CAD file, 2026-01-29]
STLs/K1-FILAMENT-CUTTER+POOP-CHUTE/Poop Shoot (Descarga)/descarga.stl
44.3 x 32.3 x 101.7

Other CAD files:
STLs/K1-FILAMENT-CUTTER+POOP-CHUTE/Enrolador de Molas/enrolador-6mm.stl
STLs/TurtleNeck-main/STLs/lid.stl
STLs/HUB-3x1-PTFE-SENSOR.stl
STLs/K1-FILAMENT-CUTTER+POOP-CHUTE/Extruder/bloco.stl
STLs/COLETOR-FILAMENTO_2.stl
STLs/FILAMENT_BUFFER_MOUNT.stl
STLs/K1-FILAMENT-CUTTER+POOP-CHUTE/Extruder/braco_old.stl
STLs/K1C POOP CHUTE.stl
STLs/TurtleNeck-main/STLs/TN_horizontal mount.stl

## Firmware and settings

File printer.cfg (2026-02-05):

# K1C
# Printer_size: 220x220x250
# Version: v2.0.5
# CreateDate: 2023/09/05
# Nozzle_mcu: chip: GD32F303CBT6
#             version: CR-K1-MAX-NOZZLE-V1.2.0
# Leveling_mcu: chip: GD32E230F8P6
#             version: CR-K1-MAX-LEVELING-V1.1.0
# mcu: chip: GD32F303RET6
#      version: CR4CU220812S12

[include sensorless.cfg]
[include gcode_macro.cfg]
[include printer_params.cfg]
[include Helper-Script/save-zoffset.cfg]
[include Helper-Script/useful-macros.cfg]
[include chameleon.cfg]


# [mcu arduino]
# serial: /dev/ttyACM0
# baud: 250000
# restart_method: arduino

# [static_digital_output disable_buttons]
# pins: !arduino:PB0 # Apenas um pino qualquer para "prender" a config

[include 3dchameleon.cfg]


[mcu]
serial: /dev/ttyS7
baud: 230400
restart_method: command

[mcu nozzle_mcu]
serial: /dev/ttyS1
baud: 230400
restart_method: command

[mcu leveling_mcu]
serial: /dev/ttyS9
baud: 230400
restart_method: command

[verify_heater extruder]
[verify_heater heater_bed]
check_gain_time: 120
heating_gain: 1.0
hysteresis: 10

[mcu rpi]
serial: /tmp/klipper_host_mcu

# [mcu chameleon]
# serial: /dev/serial/by-id/usb-1a86_USB_Serial-if00-port0

[bl24c16f]
i2c_mcu: rpi
i2c_bus: i2c.2
i2c_speed: 400000

[idle_timeout]
timeout: 99999999

[virtual_sdcard]
path: /usr/data/printer_data/gcodes

[gcode_arcs]
resolution: 1.0

[temperature_sensor mcu_temp]
sensor_type: temperature_mcu
min_temp: 0
max_temp: 100

[temperature_sensor chamber_temp]
sensor_type: Generic 3950
#sensor_type: EPCOS 100K B57560G104F
sensor_pin: PC5
min_temp: 0
max_temp: 125

[duplicate_pin_override]
pins: PC0, PC5

[temperature_fan chamber_fan]
pin: PC0
cycle_time: 0.0100
hardware_pwm: false
max_power: 1
shutdown_speed: 0
sensor_type: Generic 3950
#sensor_type: EPCOS 100K B57560G104F
sensor_pin: PC5
min_temp: -200
max_temp: 80
control: watermark
max_delta: 2
target_temp: 55.0
max_speed: 1.0
min_speed: 0.0

[stepper_x]
step_pin: PC2
dir_pin: !PB9
enable_pin: !PC3
microsteps: 32
rotation_distance: 40
endstop_pin: tmc2209_stepper_x:virtual_endstop
position_endstop: 229
position_min: -5
position_max: 229
homing_speed: 30
homing_retract_dist:0

[tmc2209 stepper_x]
uart_pin:PA9
interpolate: True
run_current:1.5
hold_current:1.0
sense_resistor: 0.100
stealthchop_threshold: 0
uart_address:3
diag_pin: ^PB12
# driver_IHOLDDELAY: 8
# driver_TPOWERDOWN: 20
# driver_TBL: 1
# driver_TOFF: 1
# driver_HEND: 0
# driver_HSTRT: 7
driver_SGTHRS: 75

[stepper_y]
step_pin: PB8
dir_pin: !PB7
enable_pin: !PC3
microsteps: 32
rotation_distance: 40
endstop_pin: tmc2209_stepper_y:virtual_endstop
position_endstop: -0.5
position_min: -0.5
position_max: 227
homing_speed: 30
homing_retract_dist:0

[tmc2209 stepper_y]
uart_pin:PA10
interpolate: True
run_current:1.5
hold_current:1.0
sense_resistor: 0.100
stealthchop_threshold: 0
uart_address:3
diag_pin: ^PB13
# driver_IHOLDDELAY: 8
# driver_TPOWERDOWN: 20
# driver_TBL: 1
# driver_TOFF: 1
# driver_HEND: 0
# driver_HSTRT: 7
driver_SGTHRS: 75

[stepper_z]
step_pin: PB6
dir_pin: !PB5
enable_pin: !PC3
microsteps: 16
rotation_distance:8
gear_ratio: 64:20
endstop_pin: tmc2209_stepper_z:virtual_endstop# PA15   #probe:z_virtual_endstop
position_endstop: 0
position_max: 255
position_min: -5

[tmc2209 stepper_z]
uart_pin: PA11
uart_address: 3
run_current: 0.8
diag_pin: ^PB14
stealthchop_threshold: 0
sense_resistor: 0.100
# driver_IHOLDDELAY: 8
# driver_TPOWERDOWN: 20
# driver_TBL: 1
# driver_TOFF: 1
# driver_HEND: 2
# driver_HSTRT: 2
driver_SGTHRS: 0

[extruder]
max_extrude_only_distance: 1000.0
max_extrude_cross_section: 80
step_pin: nozzle_mcu:PB1
dir_pin: nozzle_mcu:PB0
enable_pin: !nozzle_mcu:PB2
microsteps: 16
rotation_distance: 6.9
nozzle_diameter: 0.400
filament_diameter: 1.750
heater_pin: nozzle_mcu:PB7
sensor_type: EPCOS 100K B57560G104F
sensor_pin: nozzle_mcu:PA0
pressure_advance: 0.04
pressure_advance_smooth_time: 0.040
control: pid
pid_Kp: 25.013
pid_Ki: 2.566
pid_Kd: 60.966
min_temp: 0
max_temp: 320

[tmc2209 extruder]
uart_pin: nozzle_mcu:PB11
tx_pin: nozzle_mcu:PB10

uart_address: 3
run_current: 0.40
sense_resistor: 0.150
stealthchop_threshold: 0
# driver_IHOLDDELAY: 8
# driver_TPOWERDOWN: 20
# driver_TBL: 2
# driver_TOFF: 3
# driver_HEND: 0
# driver_HSTRT: 5

[heater_bed]
heater_pin: PB10
sensor_type: EPCOS 100K B57560G104F
sensor_pin: PC4
control: watermark
# control: pid
# pid_kp: 27
# pid_ki: 0.08
# pid_kd: 0
min_temp: 0
max_temp: 115




[filament_switch_sensor filament_sensor]
pause_on_runout: true
switch_pin: !PC15
runout_gcode:
  {% if printer.extruder.can_extrude|lower == 'true' %}
    G91
    G0 E30 F600
    G90
  {% endif %}

[filament_switch_sensor filament_sensor_2]
pause_on_runout: true
switch_pin: !nozzle_mcu:PA10

[multi_pin heater_fans]
pins:nozzle_mcu:PB5,PB2

[heater_fan hotend_fan]
pin: multi_pin:heater_fans
heater: extruder
heater_temp: 40

[static_digital_output my_fan_output_pins]
pins: nozzle_mcu: PB6

[output_pin fan0]
pin: !nozzle_mcu: PB8
pwm: True
cycle_time: 0.0100
hardware_pwm: false
value: 0.00
scale: 255
shutdown_value: 0.0

[output_pin fan1]
pin: PC0
pwm: True
cycle_time: 0.0100
hardware_pwm: false
value: 0.00
scale: 255
shutdown_value: 0.0

[output_pin fan2]
pin: PB1
pwm: True
cycle_time: 0.0100
hardware_pwm: false
value: 0.00
scale: 255
shutdown_value: 0.0

[output_pin LED]
pin:PB0
pwm: True
cycle_time: 0.010
value: 1

[adxl345]
cs_pin: nozzle_mcu:PA4
spi_speed: 5000000
axes_map: x,-z,y
spi_software_sclk_pin: nozzle_mcu:PA5
spi_software_mosi_pin: nozzle_mcu:PA7
spi_software_miso_pin: nozzle_mcu:PA6

[resonance_tester]
accel_chip: adxl345
accel_per_hz: 75
# min_freq: 30
# max_freq: 100
probe_points:
   110,110,10

# [prtouch_v2]  # K1
# pr_version: 1
# step_base: 2
# z_offset: 0 
# noz_ex_com: 0.06
# tilt_corr_dis: 0
# tri_min_hold: 2500
# tri_max_hold: 6000
# pres_cnt: 4
# pres0_clk_pins: leveling_mcu:PA5
# pres0_sdo_pins: leveling_mcu:PA1
# pres1_clk_pins: leveling_mcu:PA2
# pres1_sdo_pins: leveling_mcu:PA0
# pres2_clk_pins: leveling_mcu:PA6
# pres2_sdo_pins: leveling_mcu:PA3
# pres3_clk_pins: leveling_mcu:PA7
# pres3_sdo_pins: leveling_mcu:PA4
# show_msg: False
# step_swap_pin: PC10
# pres_swap_pin: leveling_mcu:PB1
# g28_wait_cool_down: true
# pa_clr_down_mm: -0.15
# clr_noz_start_x: 87
# clr_noz_start_y: 225
# clr_noz_len_x: 46
# clr_noz_len_y: 1
# speeds: 2.5,1.0
# tri_hftr_cut: 2,1
# tri_lftr_k1: 0.70,0.30
# tri_try_max_times: 10
# tri_min_hold: 2500,20000
# tri_max_hold: 6000,60000

# clr_noz_quick: true
# clr_quick_high:0.7
# clr_xy_quick_spd:100
# clr_quick_times:10
# clr_quick_react_dis:5



[prtouch_v2]  # K1
pr_version: 1
step_base: 2
z_offset: 0 
noz_ex_com: 0.05
tilt_corr_dis: 0.03
tri_min_hold: 2000
tri_max_hold: 6000
pres_cnt: 4
pres0_clk_pins: leveling_mcu:PA5
pres0_sdo_pins: leveling_mcu:PA1
pres1_clk_pins: leveling_mcu:PA2
pres1_sdo_pins: leveling_mcu:PA0
pres2_clk_pins: leveling_mcu:PA6
pres2_sdo_pins: leveling_mcu:PA3
pres3_clk_pins: leveling_mcu:PA7
pres3_sdo_pins: leveling_mcu:PA4
show_msg: False
step_swap_pin: PC10
pres_swap_pin: leveling_mcu:PB1
g28_wait_cool_down: true
pa_clr_down_mm: -0.15
# clr_noz_start_x: 95
# clr_noz_start_y: 221
# clr_noz_len_x: 40
# clr_noz_len_y: 2
speeds: 2.5,0.5
tri_hftr_cut: 2,1
tri_lftr_k1: 0.70,0.30
tri_try_max_times: 10
tri_min_hold: 2000,20000
tri_max_hold: 6000,60000

# Configuração da limpeza do bico (parâmetros oficiais)
clr_noz_start_x: 80              # X inicial da limpeza
clr_noz_start_y: 190             # Y inicial da limpeza
clr_noz_len_x: 36                # Comprimento X da limpeza
clr_noz_len_y: 2                 # Comprimento Y da limpeza

# Modo limpeza rápida
clr_noz_quick: true
clr_quick_high: 0.7              # Altura da limpeza rápida (mm)
clr_xy_quick_spd: 100            # Velocidade XY (mm/min)
clr_quick_times: 10              # Número de ciclos
clr_quick_react_dis: 5           # Distância de reação

[bed_mesh]
speed: 150
mesh_min: 5,5
#mesh_max: 215,215 # ORIGINAL
mesh_max: 215,205
probe_count: 5,5
fade_start: 5.0
fade_end: 50.0

[display_status]

[printer]
kinematics: corexy
max_velocity: 600
max_accel: 20000
max_accel_to_decel: 20000
max_z_velocity: 10
square_corner_velocity: 5.0
max_z_accel: 300
square_corner_max_velocity: 200.0
[pause_resume]
# recover_velocity: 500.

[exclude_object]
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

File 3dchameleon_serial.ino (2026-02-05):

/* Firmware 3DChameleon Mk4.1 - Versão Arduino Uno CNC Shield com Interface Serial

Adaptado para Arduino Uno com CNC Shield v3 para integração com Klipper
- Eixo Z: Motor da extrusora (alimentação de filamento)
- Eixo X: Motor do seletor (seleção de ferramenta)
- Serial: Comunicação com Klipper (9600 baud)
- OLED: Removido (usando saída Serial)
- Servo: Pino 11 (cortador de filamento/coletor de purga)

Pinos do Hardware:
- Controle de Motores: Eixo Z (D4/D7/D12), Eixo X (D2/D5/D8)
- Servo: D11 (coletor de purga)
- Sensores de Filamento (NC): 
  * T0: D9 (X Endstop)
  * T1: D10 (Y Endstop)
  * T2: D13 (SpnDir)
  * Hotend: A3 (CoolEnd)
- Sensor de Alimentação de Filamento (NO): T1: A2 (Resume)
- Sensores de Buffer (NC): A0 (HOLD), A1 (ABORT)

Original Copyright 2024 William J. Steele

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
Comandos Serial (enviados do Klipper):

Comandos SELECT (apenas seleção de ferramenta):
T0 - Seleciona T0 (move seletor apenas para posição T0)
T1 - Seleciona T1 (move seletor apenas para posição T1)
T2 - Seleciona T2 (move seletor apenas para posição T2)
T3 - Seleciona T3 (move seletor apenas para posição T3)

Comandos LOAD/UNLOAD (trabalham na posição da ferramenta atual):
LOAD <distância> - Carrega filamento na posição da ferramenta atual com distância especificada (mm)
  * Usa sensor de filamento do hotend (A3) para detectar filamento, depois continua com distância especificada
UNLOAD - Descarrega filamento até sensor específico da ferramenta detectar ausência de filamento (parada automática)
  * T0: Usa sensor no D9 (X Endstop) - sensor NC (LOW = sem filamento)
  * T1: Usa sensor no D10 (Y Endstop) - sensor NC (LOW = sem filamento)
  * T2: Usa sensor no D13 (SpnDir) - sensor NC (LOW = sem filamento)
  * Para automaticamente quando sensor indica que filamento saiu
UNLOAD <distância> - Descarrega filamento da posição da ferramenta atual com distância especificada (mm) - modo legado
UNLOAD_RETRACAO <distância> - Descarrega filamento com velocidade fixa (5 mm/s) para sincronização de retração com Klipper

Carregamento Baseado em Sensor:
- loadUntilSensorAlimentacaoDeFilamento(toolNumber): Carrega filamento até sensor específico da ferramenta detectar presença
  * Move automaticamente seletor para ferramenta, carrega até sensor, depois retorna para posição original
  * T0: D9, T1: D10, T2: D13 (sensores NC - HIGH = filamento presente)

Comandos do Sistema:
HOME - Faz home apenas do seletor
IDLE - Move seletor para posição idle
COLETOR_ON - Abre coletor de purga (gira por 1 segundo)
COLETOR_OFF - Fecha coletor de purga (gira por 1 segundo)


Posições Idle 
T0 → idle em T2 
T1 → idle em T3
T2 → idle em T0
T3 → idle em T1
*/

#include <SPI.h>
#include <Servo.h>
#include <EEPROM.h>


// OLED removido - usando saída Serial ao invés

// CNC Shield não possui expansor SX1509 IO

// Define números dos pinos - Arduino Uno com CNC Shield
// Eixo Z para motor da extrusora (alimentação de filamento)
#define extEnable 12   // Z_ENABLE
#define extStep 4      // Z_STEP
#define extDir 7       // Z_DIR

// Eixo X para motor do seletor (seletor de ferramenta)
#define selEnable 8    // X_ENABLE
#define selStep 2      // X_STEP
#define selDir 5       // X_DIR

// Pino PURGA_COLETOR (compatível com Arduino Uno)
#define PURGA_COLETOR_PIN 11 // Coletor de purga -  Z+ Endstop da placa CNCShield

// Pino do sensor de filamento (NC - Normalmente Fechado)
#define FILAMENT_SENSOR_PIN A3 // CoolEnd da placa CNCShield

// Sensores de filamento específicos por ferramenta (NC - Normalmente Fechado)
// Usado para comando UNLOAD para detectar quando filamento saiu da ferramenta
// Lógica: HIGH = filamento presente, LOW = sem filamento
#define FILAMENT_SENSOR_T0_PIN 9   // Sensor de filamento T0 - X Endstop da placa CNCShield
#define FILAMENT_SENSOR_T1_PIN 10  // Sensor de filamento T1 - Y Endstop da placa CNCShield
#define FILAMENT_SENSOR_T2_PIN 13  // Sensor de filamento T2 - SpnDir da placa CNCShield

// Sensor de alimentação de filamento (detecta presença de filamento na ferramenta)
// Usado para monitorar se filamento está pré-carregado nas ferramentas
//#define FILAMENT_ALIMENTATION_SENSOR_T0_PIN A4 // Sensor de alimentação de filamento - CoolEnd da placa CNCShield
#define FILAMENT_ALIMENTATION_SENSOR_T1_PIN A2 // Sensor de alimentação T1 - NO (Normalmente Aberto) - Resume da placa CNCShield
// Lógica: HIGH (1) = filamento presente, LOW (0) = sem filamento
//#define FILAMENT_ALIMENTATION_SENSOR_T2_PIN A5 // Sensor de alimentação de filamento T2 - SpnDir da placa CNCShield
bool PRESENCA_FILAMENTO_T0 = false;
bool PRESENCA_FILAMENTO_T1 = false;
bool PRESENCA_FILAMENTO_T2 = false;

// Pinos do sistema de buffer (NC - Normalmente Fechado)
#define BUFFER_EMPTY_PIN A1      // ABORT - Microswitch 1 - Buffer vazio - HOLD da placa CNCShield
#define BUFFER_FULL_PIN A0       // HOLD - Microswitch 2 - Buffer cheio - ABORT da placa CNCShield

// Constantes do sistema de buffer
#define BUFFER_CHECK_INTERVAL 100   // Verificar buffer a cada 0.1s (resposta mais rápida)

bool imprimindo = false;

// Variaveis para controle do motor
const int counterclockwise = HIGH;
const int clockwise = !counterclockwise;

const int stepsPerRev = 200;
const int microSteps = 16;
const int speedDelay = 170;     // Original: 170, Faster: 85, Fastest: 40
const int selectorSpeedDelay = 60; // Velocidade específica para o seletor (3x mais rápido)

const int defaultBackoff = 5;

Servo filamentCutter;  // cria objeto servo para controlar um servo
int cutterPos = 0;    // variável para armazenar a posição do servo
bool reverseServo = true;

// Coletor de purga (360 graus servo)
const int COLETOR_STOP = 1500;           // Servo parado
const int COLETOR_OPEN_SPEED = 1300;     // Velocidade para abrir coletor (sentido horario)
const int COLETOR_CLOSE_SPEED = 1700;    // Velocidade para fechar coletor (sentido anti-horario)
const int COLETOR_OPEN_TIME = 300;       // Tempo para abrir coletor em ms (0.5 segundo)
const int COLETOR_CLOSE_TIME = 180;      // Tempo para fechar coletor em ms (0.5 segundo)

int currentExtruder = -1;
int nextExtruder = 0;
int lastExtruder = -1;
int tempExtruder = -1;

// Variáveis do sistema de buffer
unsigned long lastBufferCheck = 0;
bool lastBufferEmptyState = false;  // Estado anterior do sensor vazio
bool lastBufferFullState = false;   // Estado anterior do sensor cheio

// Timeout de idle baseado em inatividade do buffer (1 minuto = 60000ms)
#define IDLE_TIMEOUT 120000  // 1 minuto sem uso do buffer = impressora parada
unsigned long lastBufferActivity = 0;  // Última vez que o buffer foi usado
bool isInIdleMode = false;  // Flag para saber se está em modo idle


int loaderMode = 1;  //(0= direto, 1=loader/unloader - modo automático)

// Variáveis de comunicação serial
String serialBuffer = "";
bool commandReceived = false;

// Configurações de distância
long distance = 10;

// Cálculo de passos por mm (calibrado para sua configuração)
const float STEPS_PER_MM = 151.0; // Calibrado: comando 100mm = 51mm real -> precisa ~2x mais passos

long unloadDistance = stepsPerRev * microSteps * distance;  // são 10 voltas - cerca de 10"
long loadDistance   = unloadDistance * 1.1;           // são 11 voltas - cerca de 11"

int address = 0;
byte value;


// Endereços EEPROM
#define EEPROM_EXTRUDER_ADDR 0  // Endereço para armazenar extrusora atual

// Funções para salvar/carregar extrusora da EEPROM
void saveCurrentExtruder(int extruder) {
  EEPROM.write(EEPROM_EXTRUDER_ADDR, extruder + 1); // +1 porque EEPROM não pode armazenar -1
}

int loadSavedExtruder() {
  int saved = EEPROM.read(EEPROM_EXTRUDER_ADDR);
  return saved - 1; // -1 para restaurar valor original (-1 significa sem extrusora)
}

void setup()
{

  // Saída Serial ao invés de OLED
  Serial.begin(9600);

  Serial.println("3DChameleon Mk4 Ready");

  // Configura os pinos como Saídas
  pinMode(extEnable, OUTPUT);
  pinMode(extStep, OUTPUT);
  pinMode(extDir, OUTPUT);

  pinMode(selEnable, OUTPUT);
  pinMode(selStep, OUTPUT);
  pinMode(selDir, OUTPUT);

  // Configuração do sensor de filamento (NC - Normalmente Fechado, INPUT_PULLUP)
  pinMode(FILAMENT_SENSOR_PIN, INPUT_PULLUP);

  // Configuração dos sensores de filamento específicos por ferramenta (NC - Normalmente Fechado, INPUT_PULLUP)
  pinMode(FILAMENT_SENSOR_T0_PIN, INPUT_PULLUP);
  pinMode(FILAMENT_SENSOR_T1_PIN, INPUT_PULLUP);
  pinMode(FILAMENT_SENSOR_T2_PIN, INPUT_PULLUP);

  // Configuração do sensor de alimentação de filamento (NO - Normalmente Aberto, INPUT_PULLUP)
  //pinMode(FILAMENT_ALIMENTATION_SENSOR_T0_PIN, INPUT_PULLUP);
  pinMode(FILAMENT_ALIMENTATION_SENSOR_T1_PIN, INPUT_PULLUP);
  //pinMode(FILAMENT_ALIMENTATION_SENSOR_T2_PIN, INPUT_PULLUP);

  //Verifica quais filamentos estão pre alimentados
  //PRESENCA_FILAMENTO_T0 = (digitalRead(FILAMENT_ALIMENTATION_SENSOR_T0_PIN) == HIGH);
  PRESENCA_FILAMENTO_T1 = (digitalRead(FILAMENT_ALIMENTATION_SENSOR_T1_PIN) == HIGH); // HIGH = filamento presente, LOW = sem filamento
  //PRESENCA_FILAMENTO_T2 = (digitalRead(FILAMENT_ALIMENTATION_SENSOR_T2_PIN) == HIGH);

  // Configuração dos sensores de buffer (NC - Normalmente Fechado, INPUT_PULLUP)
  pinMode(BUFFER_EMPTY_PIN, INPUT_PULLUP);  // A0 (HOLD)
  pinMode(BUFFER_FULL_PIN, INPUT_PULLUP);   // A1 (ABORT)

  // Inicializa estados dos sensores de buffer
  lastBufferEmptyState = (digitalRead(BUFFER_EMPTY_PIN) == HIGH);
  lastBufferFullState = (digitalRead(BUFFER_FULL_PIN) == HIGH);

  // Inicializa timer de atividade do buffer e modo idle
  lastBufferActivity = millis();
  isInIdleMode = false;

  // Inicializa servo para cortador de filamento/coletor de purga
  filamentCutter.attach(PURGA_COLETOR_PIN);
  filamentCutter.writeMicroseconds(COLETOR_STOP); // Inicia parado

  // Inicializa motor da extrusora como DESABILITADO (HIGH = desabilitado)
  digitalWrite(extEnable, HIGH); // Garante que motor da extrusora inicia desabilitado

  // Trava o seletor energizando-o - mantém travado 100% do tempo
  digitalWrite(selEnable, LOW); // Sempre travado

  // Auto-home na inicialização para estabelecer posição conhecida
  homeSelector();
  Serial.println("Home OK");

  // Carrega extrusora salva da EEPROM e posiciona nela
  lastExtruder = loadSavedExtruder();
  if(lastExtruder >= 0 && lastExtruder <= 2) {  // Apenas T0, T1, T2 disponíveis

    // Move para a posição da extrusora salva
    currentExtruder = lastExtruder;
    gotoExtruder(0, currentExtruder);  // Da posição home (0) para posição salva

    // Mantém o seletor na posição da ferramenta ativa
    Serial.print("T");
    Serial.print(lastExtruder);
    Serial.println(" loaded");
  } else {
    Serial.println("Stay T0");
    currentExtruder = 0;
    lastExtruder = 0;
    saveCurrentExtruder(currentExtruder);
  }
  
  Serial.print("T0: ");
  if(PRESENCA_FILAMENTO_T0) {
    Serial.println("Ocupado");
  } else {
    Serial.println("Livre");
  }
  Serial.print("\nT1: ");
  if(PRESENCA_FILAMENTO_T1) {
    Serial.println("Ocupado");
  } else {
    Serial.println("Livre");
  }
  Serial.print("\nT2: ");
  if(PRESENCA_FILAMENTO_T2) {
    Serial.println("Ocupado");
  } else {
    Serial.println("Livre");
  }

  Serial.println("\n\nCmd: T0-T2\nHOME\nIDLE\nLOAD <mm>\nUNLOAD (sensor) ou UNLOAD <mm>\nUNLOAD_RETRACAO <mm>\nCOLETOR_ON/OFF\nSTART_PRINT\nSTOP_PRINT\nTEST_SPEED\n\n");

}

void loop()
{
  // Check for serial commands from Klipper
  while (Serial.available() > 0)
  {
    char incomingChar = Serial.read();
    if (incomingChar == '\n' || incomingChar == '\r')
    {
      if (serialBuffer.length() > 0)
      {
        commandReceived = true;
        break;
      }
    }
    else
    {
      serialBuffer += incomingChar;
    }
  }

  // Process received command
  if (commandReceived)
  {
    Serial.print("Comando: ");
    Serial.println(serialBuffer);

    // RESETAR TIMER DE INATIVIDADE - houve atividade do usuário/Klipper
    lastBufferActivity = millis();
    isInIdleMode = false;  // SAIR DO MODO IDLE
    // Serial.println("Atividade detectada (comando serial) - saindo do idle");

    processSerialCommand(serialBuffer);
    serialBuffer = "";
    commandReceived = false;
  }

  // ========== MONITORAMENTO DE MUDANÇAS DO BUFFER ==========
  monitorBufferStateChanges();

  // ========== MONITORAMENTO AUTOMÁTICO DO BUFFER ==========
  unsigned long currentTime = millis();
  if (currentTime - lastBufferCheck >= BUFFER_CHECK_INTERVAL) {
    maintainBuffer();
    lastBufferCheck = currentTime;
  }

  // ========== MONITORAMENTO DE IDLE (sempre ativo) ==========
  //checkIdleTimeout(currentTime);

  //Check se precisa alimentar novo filamento adicionado antes do 3dchameleon
  monitorFilamentAlimentation();

  // small delay to prevent overwhelming the processor
  delay(10);
}



void monitorFilamentAlimentation() {
  if(imprimindo) {
    return;
  }else{
    // //Verifica se T0 está alimentado
    // if (digitalRead(FILAMENT_ALIMENTATION_SENSOR_T0_PIN) == HIGH && PRESENCA_FILAMENTO_T0 == false) {
    //   Serial.println("Alimentando T0");
    //   loadUntilSensorAlimentacaoDeFilamento(0); // Alimenta T0 com novo filamento
    //   PRESENCA_FILAMENTO_T0 = true;
    // }
    // if (digitalRead(FILAMENT_ALIMENTATION_SENSOR_T0_PIN) == LOW && PRESENCA_FILAMENTO_T0 == true) {
    //   Serial.println("T0 Livre");
    //   PRESENCA_FILAMENTO_T0 = false;
    // }
    
    //Verifica se T1 está alimentado
    // Sensor: HIGH (1) = filamento presente, LOW (0) = sem filamento
    if (digitalRead(FILAMENT_ALIMENTATION_SENSOR_T1_PIN) == HIGH && PRESENCA_FILAMENTO_T1 == false) {
      Serial.println("Alimentando T1");
      loadUntilSensorAlimentacaoDeFilamento(1); // Alimenta T1 com novo filamento
      PRESENCA_FILAMENTO_T1 = true;
    }
    if (digitalRead(FILAMENT_ALIMENTATION_SENSOR_T1_PIN) == LOW && PRESENCA_FILAMENTO_T1 == true) {
      Serial.println("T1 Livre");
      PRESENCA_FILAMENTO_T1 = false;
    }
    
    // //Verifica se T2 está alimentado
    // if (digitalRead(FILAMENT_ALIMENTATION_SENSOR_T2_PIN) == HIGH && PRESENCA_FILAMENTO_T2 == false) {
    //   Serial.println("Alimentando T2");
    //   loadUntilSensorAlimentacaoDeFilamento(2); // Alimenta T2 com novo filamento
    //   PRESENCA_FILAMENTO_T2 = true;
    // }
    // if (digitalRead(FILAMENT_ALIMENTATION_SENSOR_T2_PIN) == LOW && PRESENCA_FILAMENTO_T2 == true) {
    //   Serial.println("T2 Livre");
    //   PRESENCA_FILAMENTO_T2 = false;
    // }
  }
}

// Funções do coletor de purga
void coletorOn() {
  filamentCutter.writeMicroseconds(COLETOR_OPEN_SPEED);

  // Gira por tempo definido para abrir
  delay(COLETOR_OPEN_TIME);

  // Para o servo
  filamentCutter.writeMicroseconds(COLETOR_STOP);
  Serial.println("Coletor ON");
}

void coletorOff() {
  filamentCutter.writeMicroseconds(COLETOR_CLOSE_SPEED);

  // Gira por tempo definido para fechar
  delay(COLETOR_CLOSE_TIME);

  // Para o servo
  filamentCutter.writeMicroseconds(COLETOR_STOP);
  Serial.println("Coletor OFF");
}

// ========== SISTEMA DE BUFFER DE FILAMENTO ==========

// Monitora mudanças de estado dos sensores do buffer
void monitorBufferStateChanges() {
  bool currentEmptyState = (digitalRead(BUFFER_EMPTY_PIN) == HIGH);
  bool currentFullState = (digitalRead(BUFFER_FULL_PIN) == HIGH);

  // Verifica mudança no sensor de buffer vazio
  if (currentEmptyState != lastBufferEmptyState) {
    Serial.print("Empty: ");
    Serial.print(lastBufferEmptyState ? "ON" : "OFF");
    Serial.print("->");
    Serial.println(currentEmptyState ? "ON" : "OFF");

    // Qualquer mudança no buffer = atividade, resetar timer de inatividade
    lastBufferActivity = millis();
    isInIdleMode = false;  // SAIR DO MODO IDLE

    lastBufferEmptyState = currentEmptyState;
  }

  // Verifica mudança no sensor de buffer cheio
  if (currentFullState != lastBufferFullState) {
    Serial.print("Full: ");
    Serial.print(lastBufferFullState ? "ON" : "OFF");
    Serial.print("->");
    Serial.println(currentFullState ? "ON" : "OFF");

    // Mudança no sensor cheio também é atividade
    lastBufferActivity = millis();
    isInIdleMode = false;  // SAIR DO MODO IDLE

    lastBufferFullState = currentFullState;
  }

  // Verifica mudança no sensor de buffer cheio
  if (currentFullState != lastBufferFullState) {
    Serial.print("Full: ");
    Serial.print(lastBufferFullState ? "ON" : "OFF");
    Serial.print("->");
    Serial.println(currentFullState ? "ON" : "OFF");
    lastBufferFullState = currentFullState;
  }
}

// Mantém buffer carregado quando necessário (automático)
void maintainBuffer() {
  bool filamentInHotend = (digitalRead(FILAMENT_SENSOR_PIN) == HIGH);
  if (!filamentInHotend) return;  // Sem filamento no hotend, não faz nada

  bool bufferEmpty = (digitalRead(BUFFER_EMPTY_PIN) == HIGH);
  unsigned long currentTime = millis();

  // Se buffer está vazio, alimentar imediatamente (atividade normal de impressão)
  if (bufferEmpty) {
    Serial.println("Loading Buffer");

    // Resetar timer de inatividade (houve atividade)
    lastBufferActivity = currentTime;

    // VERIFICAÇÃO CRÍTICA: Seletor deve estar na posição da ferramenta ativa
    if (currentExtruder != lastExtruder) {
      Serial.print("Movendo para T");
      Serial.print(lastExtruder);
      gotoExtruder(currentExtruder >= 0 ? currentExtruder : 0, lastExtruder);
      currentExtruder = lastExtruder;
    }

    // Alimenta o buffer se o seletor estiver na posição correta
    if (currentExtruder == lastExtruder) {
      feedBuffer();
      Serial.println("Buffer recarregado");
    } else {
      Serial.println("ERRO: Seletor error!");
    }
  }

  // Verificar idle timeout baseado em inatividade
  //checkIdleTimeout(currentTime);
}

// Verifica se deve ir para idle baseado em inatividade geral
// void checkIdleTimeout(unsigned long currentTime) {
//   return;
//   // Se já está em modo idle, não verificar timeout
//   if (isInIdleMode) {
//     return;
//   }

//   // Verificar se passou o timeout de inatividade DESDE O STARTUP
//   if ((currentTime - lastBufferActivity) >= IDLE_TIMEOUT) {
//     Serial.println("Inatividade geral detectada - indo para idle...");

//     // Verificar se já não está em idle
//     int idlePos;
//     if (lastExtruder == 0) idlePos = 2;
//     else if (lastExtruder == 1) idlePos = 3;
//     else if (lastExtruder == 2) idlePos = 0;
//     else idlePos = 2; // Default

//     // ANTES DE IR PARA IDLE: Verificar e preparar buffer se possível
//     bool filamentInHotend = (digitalRead(FILAMENT_SENSOR_PIN) == HIGH);
//     bool bufferFull = (digitalRead(BUFFER_FULL_PIN) == HIGH);

//     if (filamentInHotend && !bufferFull) {
//       Serial.println("Buffer não cheio - preparando antes de ir para idle...");

//       // Seletor deve estar na posição da ferramenta ativa para alimentar buffer
//       if (currentExtruder != lastExtruder) {
//         Serial.print("Seletor fora de posição! Movendo T");
//         Serial.print(lastExtruder);
//         Serial.println("...");
//         gotoExtruder(currentExtruder >= 0 ? currentExtruder : 0, lastExtruder);
//         currentExtruder = lastExtruder;
//         Serial.println("Seletor reposicionado");
//       }

//       // Só alimentar se estiver na posição correta
//       if (currentExtruder == lastExtruder) {
//         Serial.println("Alimentando buffer...");
//         feedBuffer();
//         Serial.println("Buffer preparado");
//       }
//     } else if (filamentInHotend && bufferFull) {
//       Serial.println("Buffer já está cheio - ok para idle");
//     } else if (!filamentInHotend) {
//       Serial.println("Sem filamento no hotend - indo para idle sem preparar buffer");
//     }

//     // IR PARA IDLE
//     if (currentExtruder != idlePos) {
//       Serial.println("Movendo seletor para idle...");
//       moveToIdle();
//     }
//     Serial.println("Seletor em idle (motor não aquece)");

//     // ATIVAR MODO IDLE - para não ficar repetindo
//     isInIdleMode = true;
//   }
// }

// Alimenta filamento para o buffer até sensor full
void feedBuffer() {
  // Direção baseada na ferramenta atual (mesma lógica do load)
  bool direction = (lastExtruder < 2) ? clockwise : counterclockwise;

  // Habilita motor do extruder
  digitalWrite(extEnable, LOW);
  digitalWrite(extDir, direction);

  long stepsFed = 0;
  long maxSteps = (long)(300.0 * STEPS_PER_MM); // Máximo 300mm de segurança
  bool bufferFull = false;

  // Velocidade lenta para controle preciso
  const int feedSpeed = speedDelay;

  while (stepsFed < maxSteps && !bufferFull) {
    // Verifica se buffer está cheio (segundo microswitch)
    if (digitalRead(BUFFER_FULL_PIN) == HIGH) {
      bufferFull = true;
      Serial.println("Buffer Full");
      break;
    }

    // Move um passo
    digitalWrite(extStep, HIGH);
    delayMicroseconds(feedSpeed);
    digitalWrite(extStep, LOW);
    delayMicroseconds(feedSpeed);

    stepsFed++;
  }

  // Desabilita motor
  digitalWrite(extEnable, HIGH);

  if (!bufferFull) {
    Serial.println("ERRO: Buffer nao cheio!");
  } else {
    float distanceFed = (float)stepsFed / STEPS_PER_MM;
    Serial.print("Buffer: ");
    Serial.print(distanceFed);
    Serial.println("mm");
  }
}
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

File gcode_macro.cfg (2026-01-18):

# K1C
# CreateDate: 2023/09/05


[gcode_macro PURGE_POSITION]
gcode:
   {% if printer.toolhead.position.z < 42 %}
       G0 Z45 F3000 ; Stelle sicher, dass Z mindestens 45 ist
   {% endif %}
   G0 X140.1 F6000 ; Bewege die X-Achse
   G0 Y218 F6000 ; Bewege die Y-Achse
   M106 P0 S255


[gcode_macro CLEAR_PURGE]
gcode:
   {% if printer.toolhead.position.z < 42 %}
       G0 Z45 F3000 ; Stelle sicher, dass Z mindestens 45 ist
   {% endif %}
   G0 X140.1 Y218 F6000 ; Poistion sicherstellen
   G0 Y218 F6000 ; etwas nach vorne, damit es sich nicht verhakt
   G4 P5000
   G92 E5 F750
   G0 X167 F600 ; langsam nach rechts zum abwischen
   G0 Y200 F600 ; fahrt von Hopper nach vorne
   G0 Y200 F6000 ;erneutes zuruckfahren
   G0 X140.1 F6000  
   G0 Y218 F3000
   G0 Y200 F10000
   G0 Y218 F3000
   G0 Y200 F10000
   G0 Y218 F3000
   G0 Y200 F10000


[gcode_macro PRINTER_PARAM]
variable_z_safe_pause: 0.0
variable_z_safe_g28: 3.0
variable_max_x_position: 220.0
variable_max_y_position: 220.0
variable_max_z_position: 250.0
variable_fans: 3
variable_auto_g29: 0
variable_fan0_min: 25
variable_fan1_min: 50
variable_fan2_min: 180
variable_fan2_speed: 0
variable_hotend_temp: 0
variable_e_min_current: 0.27
variable_cam_off_temp: 60
gcode:

[gcode_macro AUTOTUNE_SHAPERS]
variable_autotune_shapers: 'ei'
gcode:

[gcode_macro LOAD_MATERIAL_CLOSE_FAN2]
variable_fan2_value: 0
gcode:
  SAVE_GCODE_STATE NAME=myMoveState
  {% if printer['output_pin fan2'].value > 0.0 %}
    SET_GCODE_VARIABLE MACRO=LOAD_MATERIAL_CLOSE_FAN2 VARIABLE=fan2_value VALUE={printer['output_pin fan2'].value}
    M107 P2
  {% endif %}
  RESTORE_E_CURRENT

[gcode_macro LOAD_MATERIAL_RESTORE_FAN2]
gcode:
  {% set fan2_value = printer['gcode_macro LOAD_MATERIAL_CLOSE_FAN2'].fan2_value|float %}
  RESTORE_GCODE_STATE NAME=myMoveState
  {% if fan2_value > 0.0 %}
    {% set s_value = (fan2_value * 255 - printer["gcode_macro PRINTER_PARAM"].fan2_min) * 255 / (255 - printer["gcode_macro PRINTER_PARAM"].fan2_min) %}
    M106 P2 S{s_value}
    SET_GCODE_VARIABLE MACRO=LOAD_MATERIAL_CLOSE_FAN2 VARIABLE=fan2_value VALUE=0
  {% endif %}
  SET_E_MIN_CURRENT

[gcode_macro SET_E_MIN_CURRENT]
gcode:
  {% set e_current = printer['gcode_macro PRINTER_PARAM'].e_min_current %}
  M400
  SET_TMC_CURRENT STEPPER=extruder CURRENT={e_current} HOLDCURRENT={e_current}
  G4 P2000

[gcode_macro RESTORE_E_CURRENT]
gcode:
  {% set e_current = printer.configfile.settings['tmc2209 extruder'].run_current %}
  M400
  SET_TMC_CURRENT STEPPER=extruder CURRENT={e_current} HOLDCURRENT={e_current}
  G4 P2000
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

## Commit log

2026-01-01 🎉 INT COMMIT:
    [chameleon.cfg]
2026-01-01 add posição de purga
    [chameleon.cfg]
2026-01-01 add salva status posicao
    [chameleon.cfg]
2026-01-02 add servo MG996R filament cut
2026-01-13 fix refiz ambos
    [3dchameleon.cfg, chameleon.cfg, holder.step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]
2026-01-13 fix select Tx, unload and load
    [3dchameleon.cfg]
2026-01-14 muda comunicacao para serial ao invez da trigger
    [3dchameleon_serial.cfg]
2026-01-14 add corte
    [3dchameleon_serial.cfg]
2026-01-14 fix nome T
    [3dchameleon_serial.cfg]
2026-01-14 add sensor filamento no hotend
    [3dchameleon_serial.cfg]
2026-01-14 ajuste de salvamento de filamento
    [3dchameleon_serial.cfg]
2026-01-15 8 para 16 steps driver config
2026-01-15 fix tudo funcionado
    [3dchameleon_serial.cfg]
2026-01-18 Add pugra
    [3dchameleon.cfg, 3dchameleon_serial.cfg, gcode_macro.cfg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]
2026-01-21 add stls
    [3dchameleon.cfg, FILAMENT_BUFFER_MOUNT.stl, K1C POOP CHUTE.stl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]
2026-01-29 add sensor de filamento individual
    [3dchameleon_serial.cfg]
2026-01-29 update STLs
    [COLETOR-FILAMENTO_1.stl, COLETOR-FILAMENTO_2.stl, HUB-3x1-PTFE-SENSOR.stl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]
2026-02-05 fix do fix
    [3dchameleon_arduino_mcu.cfg, 3dchameleon_serial.cfg, FILAMENT_BUFFER_MOUNT_TOP.stl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]

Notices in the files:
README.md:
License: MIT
